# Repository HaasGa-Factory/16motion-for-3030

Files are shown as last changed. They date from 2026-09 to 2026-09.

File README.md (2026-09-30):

# Chariot pour profilé aluminium 3030

Ce dépôt est un fork du projet [mosomate/16motion](https://github.com/mosomate/16motion). Il ajoute une [adaptation mesurée pour un profilé 3030 de 29,83 × 29,95 mm](3030/README.md), avec les modèles FreeCAD, les STL prêts à imprimer, les vues d'assemblage et une animation du coulissement.

> Cette variante correspond au profilé mesuré pour ce prototype. Tous les profilés appelés « 3030 » n'ont pas nécessairement la même section. Consultez les limites de validation avant impression.

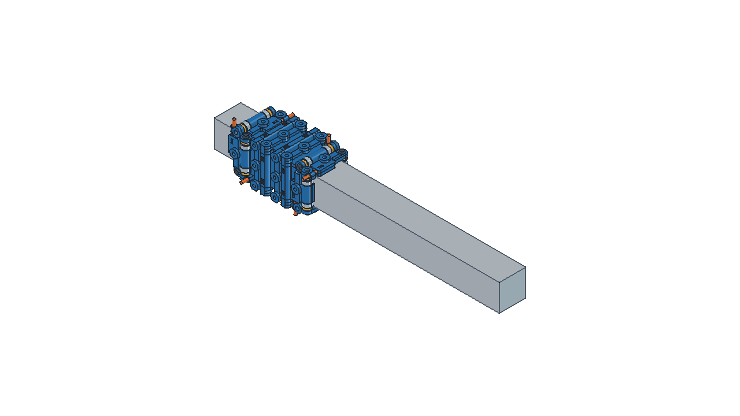
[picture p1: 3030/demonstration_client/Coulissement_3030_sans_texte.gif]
Animation du chariot 3030


## Description 16Motion ?

16Motion est un chariot configurable et imprimable en 3D pour les petits profilés aluminium jusqu'à 40 mm de largeur. Un chariot se compose de quatre plaques imprimées, assemblées autour du profilé, et de composants faciles à trouver : roulements 684 (4 × 9 × 4 mm), vis M3 et M4 et écrous M3.

Vue principale de 16Motion

Chaque plaque possède huit points de fixation permettant de monter des outils et accessoires avec des vis et écrous M3. Ils sont répartis en deux groupes : quatre **points de fixation de plaque** indiqués par les flèches jaunes et quatre **points de fixation du chariot** indiqués par les flèches violettes.

Les points de fixation du chariot traversent au moins deux plaques et augmentent donc la rigidité de l'ensemble. Si seuls les points de fixation de plaque sont utilisés, l'auteur recommande d'ajouter également des vis M3 × 16 dans quelques points de fixation du chariot.

La distance horizontale entre les points est fixée à 23 mm. La distance verticale se calcule ainsi :

`distance verticale = (largeur du profilé + 9 mm) / 2`

## Adaptation 3030 de ce fork

La section du profilé utilisé pour cette adaptation a été mesurée à **29,83 mm sur l'axe X** et **29,95 mm sur l'axe Y**. Ces deux valeurs restent séparées dans les modèles : aucune moyenne ni mise à l'échelle globale des STL n'a été appliquée.

Pour construire un chariot complet :

- imprimer **2 plaques X** depuis `Plaque_X_2983.stl` ;
- imprimer **2 plaques Y** depuis `Plaque_Y_2995.stl` ;
- imprimer **16 entretoises** depuis `Entretoise.stl`.

Les modèles, les STL, la nomenclature et les contrôles réalisés se trouvent dans le [dossier 3030](3030/README.md).

Pour imprimer directement le chariot sans préparer les plateaux soi-même, le modèle est également disponible sur [MakerWorld — 3030Pro Sliding Carriage](https://makerworld.com/fr/models/3376063-3030pro-sliding-carriage#profileId-3840481), avec le projet 3MF et son profil d'impression Bambu Studio.

## Avertissement

**L'auteur original précise qu'il n'est pas ingénieur mécanicien et que cette conception n'a pas fait l'objet d'essais professionnels. L'impression, l'assemblage et l'utilisation se font sous la responsabilité de l'utilisateur.**

Les roulements en acier roulent directement sur l'aluminium. Ils peuvent marquer ou user le profilé avec le temps. Pour une utilisation occasionnelle, l'effet peut rester limité. Pour une utilisation régulière, l'auteur conseille une légère lubrification, par exemple une fine couche de graisse au lithium.

Les vérifications CAO de cette variante ne constituent pas une validation de la capacité de charge, de l'usure ou du comportement mécanique réel. Un premier montage imprimé doit confirmer le coulissement, la précharge et l'absence de point dur sur toute la course.

## Nomenclature pour une plaque

Pour chacune des quatre plaques :

- 1 plaque imprimée en 3D ;
- 4 entretoises de roulement imprimées en 3D ;
- 2 vis M4 de longueur `largeur nominale du profilé + 10 mm` ;
- 2 vis M3 × 16 mm ;
- 2 écrous M3 autofreinés ;
- 4 roulements 684 (4 × 9 × 4 mm).

Pour la variante 3030 de ce dépôt, les axes de roulement sont des **vis M4 × 40 mm**.

## Conseils d'impression 3D

Conseils de l'auteur :

- matériau recommandé : **PETG** ;
- supports limités aux zones en contact avec le plateau ;
- épaisseur de paroi de 1 mm ;
- épaisseur supérieure et inférieure de 0,5 mm.

Les STL de la variante 3030 sont exportés en millimètres, à l'échelle 100 %, avec une déviation de surface de **0,1 mm** et une déviation angulaire de **5°**.

## Personnalisation dans FreeCAD

1. Ouvrir `Plate.FCStd` dans FreeCAD.
2. Si seule l'entretoise apparaît, afficher l'objet **Plate**. Dans ses propriétés d'apparence, sélectionner à nouveau le mode **Flat Lines**.
3. Activer temporairement **Skip recomputes** sur le document pendant la modification.
4. Dans **Spreadsheet**, modifier :
   - **Ideal extrusion width** : largeur nominale d'un côté du profilé ;
   - **Actual extrusion width** : largeur réellement mesurée.
5. Recalculer **Spreadsheet**, puis les objets dépendants **Plate**, **Spacer** et **Assets**.
6. Dans l'atelier **Mesh**, créer un maillage de **Plate** avec une déviation de surface de 0,1 mm et une déviation angulaire de 5°.
7. Créer également le maillage de **Spacer**, puis exporter les deux maillages.

Pour un profilé dont les deux dimensions mesurées diffèrent, produire deux variantes distinctes comme dans le [dossier 3030](3030/README.md). Ne pas utiliser une moyenne arbitraire.

Vidéo de personnalisation de la plaque (https://www.youtube.com/watch?v=9Bi0MCfb9tI "Personnalisation de la plaque | Série vidéo 16Motion")

## Préparation d'une plaque

1. Après impression, tarauder en M4 les trous fixes **inférieur gauche** et **supérieur droit**.
2. Insérer un écrou M3 autofreiné dans le logement situé sous un levier de précharge.
3. Introduire une vis M3 × 16 à travers le levier et la visser jusqu'à ce qu'elle touche à peine le levier.
4. Répéter l'opération pour l'autre levier.

Vidéo d'assemblage d'une plaque (https://www.youtube.com/watch?v=31CdhINwxhE "Assemblage d'une plaque | Série vidéo 16Motion")

## Assemblage du chariot

Pour le chariot complet, prévoir 16 entretoises imprimées, 16 roulements 684 et 8 vis M4 de la longueur indiquée dans la nomenclature.

1. Emboîter les quatre plaques. De longues vis M3 ou des clés Allen placées temporairement dans les points de fixation du chariot facilitent l'alignement.
2. Visser une vis M4 dans le trou taraudé d'une plaque jusqu'à ce qu'elle atteigne l'autre côté.
3. Placer une entretoise et un roulement sur le trajet de la vis M4.
4. Avancer la vis jusqu'à maintenir ce premier ensemble.
5. Ajouter une seconde entretoise et un second roulement, puis visser complètement l'axe.
6. Serrer la vis M4 sans écraser le plastique.
7. Répéter l'opération aux sept autres positions.
8. Retirer les vis ou clés utilisées temporairement pour maintenir l'alignement.

Vidéo d'assemblage du chariot (https://www.youtube.com/watch?v=4gjbtIjSXgw "Assemblage du chariot | Série vidéo 16Motion")

## Réglage de la précharge

La règle de l'auteur est simple : **aucun jeu, mais pas de tension excessive**. Régler les deux leviers d'une même paire avec une précharge aussi équilibrée que possible.

Comparaison de la précharge

1. Ébavurer légèrement les arêtes d'une extrémité du profilé.
2. Engager le chariot sur le profilé.
3. Serrer les vis d'une paire de leviers par petits incréments.
4. Faire coulisser le chariot après chaque ajustement.
5. Arrêter dès qu'une légère résistance apparaît à l'engagement.
6. Répéter pour les autres paires de leviers.

Le chariot doit encore descendre sous son propre poids lorsque le profilé est placé verticalement. S'il reste bloqué, la précharge est trop importante. Il est normal que certains roulements ne tournent pas en permanence pendant le déplacement.

Vidéo de réglage de la précharge (https://www.youtube.com/watch?v=hf6m5ihSEW8 "Réglage de la précharge | Série vidéo 16Motion")

## Licence et attribution

Conception originale : [mosomate/16motion](https://github.com/mosomate/16motion).

Ce travail est distribué sous licence [Creative Commons Attribution — Pas d'utilisation commerciale 4.0 International][cc-by-nc]. Cette adaptation conserve la même licence et n'accorde aucun droit supplémentaire.

[][cc-by-nc]

[cc-by-nc]: https://creativecommons.org/licenses/by-nc/4.0/
[cc-by-nc-image]: https://licensebuttons.net/l/by-nc/4.0/88x31.png

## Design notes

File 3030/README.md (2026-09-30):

# Adaptation 3030 — prototype mesuré

Cette variante du projet [mosomate/16motion](https://github.com/mosomate/16motion) conserve le modèle paramétrique de l'auteur et ses dimensions de quincaillerie. Elle est adaptée à **un profilé mesuré à 29,83 × 29,95 mm**, pas à tous les profilés 3030.

Coulissement du chariot

## Pièces à imprimer

| Pièce | Quantité | STL | Modèle paramétrique |
|---|---:|---|---|
| Plaque X, largeur réelle 29,83 mm | 2 | [STL X](mesures_2983_2995/Plaque_X_2983.stl) | [FreeCAD X](mesures_2983_2995/Plaque_X_2983.FCStd) |
| Plaque Y, largeur réelle 29,95 mm | 2 | [STL Y](mesures_2983_2995/Plaque_Y_2995.stl) | [FreeCAD Y](mesures_2983_2995/Plaque_Y_2995.FCStd) |
| Entretoise commune | 16 | [STL](mesures_2983_2995/Entretoise.stl) | Objet Spacer dans les modèles ci-dessus |

STL en millimètres, à imprimer à 100 %. Déviation de surface 0,1 mm et angulaire 5°. Aucun STL n'a subi de mise à l'échelle globale. Ne pas imprimer quatre fois la même variante de plaque.

## Projet Bambu Studio prêt à trancher

Le fichier [plaqueXY-entretoise.3mf](../Bambustudio/plaqueXY-entretoise.3mf) regroupe toutes les pièces nécessaires :

- **plateau 1** : 2 plaques X et 2 plaques Y ;
- **plateau 2** : 17 entretoises, dont 16 pour le montage et 1 de secours.

Réglages enregistrés dans le projet : **Bambu Lab H2S**, buse **0,4 mm**, couches de **0,20 mm**, **PETG**, deux parois, remplissage grille à 15 %, supports arborescents automatiques limités au plateau et plateau PEI texturé.

Le 3MF contient la disposition des pièces et les paramètres de tranchage, mais pas un G-code universel. Avant impression, choisir dans Bambu Studio l'imprimante, la buse, le plateau et le filament réellement installés, relancer le tranchage puis vérifier chaque couche dans l'aperçu. Sur une autre imprimante, conserver les géométries et adapter les vitesses, températures, refroidissement et supports au matériel utilisé.

## Montage et quincaillerie

La [notice en français](mesures_2983_2995/NOTICE_FR.md) précise les paramètres, l'orientation des plaques et le réglage de précharge. Pour un chariot : 16 roulements 684 (4 × 9 × 4 mm), 8 vis M4 × 40 mm, 8 vis M3 × 16 mm et 8 écrous M3 autofreinés. Les avant-trous fixes des plaques sont à tarauder M4 ; les fixations d'accessoires sont supplémentaires.

[Assemblage FreeCAD](mesures_2983_2995/Assemblage_mesure.FCStd) · [Vue éclatée FreeCAD](mesures_2983_2995/Eclate_mesure.FCStd) · [Image éclatée](mesures_2983_2995/Eclate_mesure.png)

## Démonstration du coulissement

[GIF sans texte](demonstration_client/Coulissement_3030_sans_texte.gif) · [Scène FreeCAD](demonstration_client/Demonstration_3030.FCStd) · [Macro](demonstration_client/Demonstration_3030.FCMacro)

Le GIF montre une course illustrative de 180 mm sur un rail de 320 mm. Pour déplacer la scène FreeCAD, modifier `Commande.Position` entre −90 et +90 mm. La macro s'exécute dans FreeCAD et charge l'assemblage du dossier voisin ; conserver cette arborescence. Elle propose lecture/pause, curseur et transparence des plaques. Les modèles de fabrication ne sont pas modifiés.

## Vérifications et limites

Les rapports [du prototype](mesures_2983_2995/verification_mesures.json) et [de l'animation](demonstration_client/verification.json) consignent les contrôles réalisés dans FreeCAD 1.1.3 : recalculs, géométrie, fermeture et dimensions des maillages, positions de présentation.

Le rail est une enveloppe rectangulaire simplifiée : coins et rainures ne sont pas modélisés. L'appui des roulements sur les plats est partiel. La précharge nécessite un réglage réel ; les interférences de la pose rigide sont expliquées dans la notice. L'animation impose la translation et ne simule ni rotation des roulements, ni frottements, ni déformations, ni capacité de charge. Le coulissement et la tenue mécanique restent à vérifier sur un premier montage imprimé et sur toute sa course.

## Origine et licence

Conception originale : **mosomate / 16motion**. Modifications de cette variante : valeurs du tableur pour les deux paires, exports STL, présentations d'assemblage, animation et documentation. Le `Plate.FCStd` original reste inchangé à la racine.

Licence originale **CC BY-NC 4.0**, conservée dans [LICENSE](../LICENSE). La clause non commerciale s'applique ; cette adaptation n'accorde pas de droits supplémentaires.

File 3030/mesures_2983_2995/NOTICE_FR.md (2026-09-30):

# 16motion adapté à 29,83 × 29,95 mm — prototype

Cette variante utilise les mesures du profilé du prototype : **X = 29,83 mm, Y = 29,95 mm**, ouverture G = 8,07 mm et plats P gauche/droite = 8,17 mm. Aucun calcul de moyenne entre X et Y. L'appui partiel des roulements sur les plats est conservé pour ce prototype.

## Fichiers à utiliser et quantités

| Pièce | Modèle paramétrique | STL | Quantité |
|---|---|---|---:|
| Paire X | `Plaque_X_2983.FCStd` | `Plaque_X_2983.stl` | **2** |
| Paire Y | `Plaque_Y_2995.FCStd` | `Plaque_Y_2995.stl` | **2** |
| Entretoise commune | Objet Spacer dans les deux modèles | `Entretoise.stl` | **16 au total** |

Ne pas imprimer quatre fois la même plaque et ne pas mélanger avec les STL nominaux 30/30 du modèle nominal. Marquer X ou Y au feutre sur les impressions pour les distinguer. Les petites différences se voient difficilement à l'œil.

`Assemblage_mesure.FCStd` contient les quatre plaques, 16 roulements, 16 entretoises, huit tiges M4 et huit tiges M3 de réglage. `Eclate_mesure.FCStd` s'ouvre directement dans la vue éclatée. Ces présentations utilisent des copies et liens internes, à régénérer après modification des modèles maîtres.

## Orientation des deux paires

Repère des mesures de section : **X** est la distance de 29,83 mm entre faces gauche/droite ; **Y** la distance de 29,95 mm entre faces haut/bas.

- Les deux **plaques X** se montent sur les côtés **haut et bas** ; leurs roulements roulent sur les faces gauche/droite, écartées de X.
- Les deux **plaques Y** se montent sur les côtés **gauche et droit** ; leurs roulements roulent sur les faces haut/bas, écartées de Y.

La lettre indique donc la dimension contrôlée par les roulements, et non la normale à la plaque. Dans FreeCAD, l'axe longitudinal du rail s'appelle aussi X : ce repère CAO est distinct de celui des mesures de section. Les étiquettes des plaques dans l'arbre reprennent les lettres des photos.

## Paramètres et fidélité au modèle

Dans `Spreadsheet`, **B3 (Ideal extrusion width) reste à 30 mm** sur les deux variantes. **B4 (Actual extrusion width) vaut 29,83 mm pour X et 29,95 mm pour Y**. B1 = 0,1 mm de compensation d'impression, B6 = 4 mm et B7 = 5 mm sont inchangés. Les 204 objets, les expressions, les logements et les leviers de l'auteur sont conservés. Seules les valeurs du tableur, les annotations et l'affichage changent.

Les plans d'emboîtement restent à 16 mm du centre, selon le paramétrage nominal du modèle. Les axes fixes sont à B4/2 + 4,45 mm et les axes réglables à B4/2 + 4,7 mm. Les positions des roulements et des vis de présentation suivent ces valeurs pour chaque paire. La visserie et les entretoises ne sont pas mises à l'échelle.

STL : **mm**, échelle 100 %, déviation de surface **0,1 mm**, angulaire **5°**, non relative. Maillages réimportés et comparés aux dimensions des solides ; détails dans `verification_mesures.json`. Les deux pièces sont visibles dans chaque modèle, l'entretoise étant décalée à X = 58 mm pour l'affichage seulement. Les STL sont exportés avant ce décalage.

## Quincaillerie et montage

Pour le chariot complet : **16 roulements 684 (4 × 9 × 4 mm), 8 vis M4 × 40 mm, 8 vis M3 × 16 mm et 8 écrous M3 autofreinés**, plus les fixations propres aux accessoires. Matériau conseillé par l'auteur : PETG, supports depuis le plateau. Les têtes/filets et écrous ne sont pas détaillés dans la présentation.

1. Ébavurer les pièces et dégager les fentes des leviers sans amincir leurs charnières.
2. Tarauder M4 les deux avant-trous fixes Ø3,7 mm en diagonale sur chaque plaque ; conserver les passages Ø4,2 mm.
3. Installer les écrous M3 et les vis de réglage au simple contact, sans précharger.
4. Emboîter les deux paires dans l'orientation indiquée. Ajouter les couples entretoise/roulement sur les axes M4, relief de l'entretoise tourné vers le roulement. Ne pas forcer les axes désalignés ; serrer sans écraser le plastique.
5. Vérifier que les bagues extérieures tournent librement, engager sur l'extrémité ébavurée du profilé puis régler progressivement par paires. Garder un coulissement libre sur la course entière. Selon le critère de l'auteur, le chariot doit encore descendre sous son poids sur un profilé vertical ; le retenir à la main.

## Appui partiel accepté et limites du prototype

Les K calculés valent **2,71 mm pour une face large de X** et **2,77 mm pour une face large de Y**, sous l'hypothèse de coins symétriques et des mêmes G/P sur les faces concernées. Ce ne sont pas des rayons certifiés. Avec les dimensions mesurées et l'empilement de cette présentation, la largeur projetée du roulement au-dessus du vrai plat est estimée à **environ 3,21 mm sur 4 mm**. Il s'agit d'un recouvrement géométrique, pas d'une mesure de la surface de contact sous charge.

Le rail reste une enveloppe rectangulaire de **29,83 × 29,95 mm**. La forme exacte des coins et l'intérieur des rainures n'ont pas été inventés. Les roulements fixes (objets `Roulement684_i_2` et `Roulement684_i_3`, i = 0 à 3) présentent toujours 0,05 mm de pénétration théorique dans cette enveloppe, tandis que les réglables ont 0,20 mm de jeu. Le décalage d'axes de 0,25 mm au repos nécessite déplacement et/ou inclinaison au montage. Les intersections avec les tiges simplifiées sont consignées, et les intersections M4/avant-trou doivent être distinguées du taraudage non représenté.

Les contrôles CAO vérifient solides, recalculs, maillages et interférences de la pose rigide. Ils ne simulent pas les déformations, le réglage de précharge, la charge admissible ou l'usure. Vérifier sur ce premier montage : rotation, absence de blocage et de jeu, appuis, alignement, tenue des taraudages, absence de fissure des leviers et de marques excessives sur l'aluminium. Les mesures le long de toute la course n'ont pas été fournies ; le coulissement reste donc à vérifier sur cette longueur.

Source : **mosomate / 16motion**, https://github.com/mosomate/16motion — licence **CC BY-NC 4.0**. Le modèle original est conservé à la racine du dépôt. Pour reproduire les variantes, ouvrir une copie de `Plate.FCStd`, régler B3 à 30 mm et B4 à 29,83 mm (paire X) ou 29,95 mm (paire Y), puis recalculer le tableur, Plate, Spacer et Assets. Exporter Plate et Spacer avec les réglages de maillage indiqués ci-dessus. Les documents de présentation sont des copies de formes et doivent être actualisés séparément après toute modification.

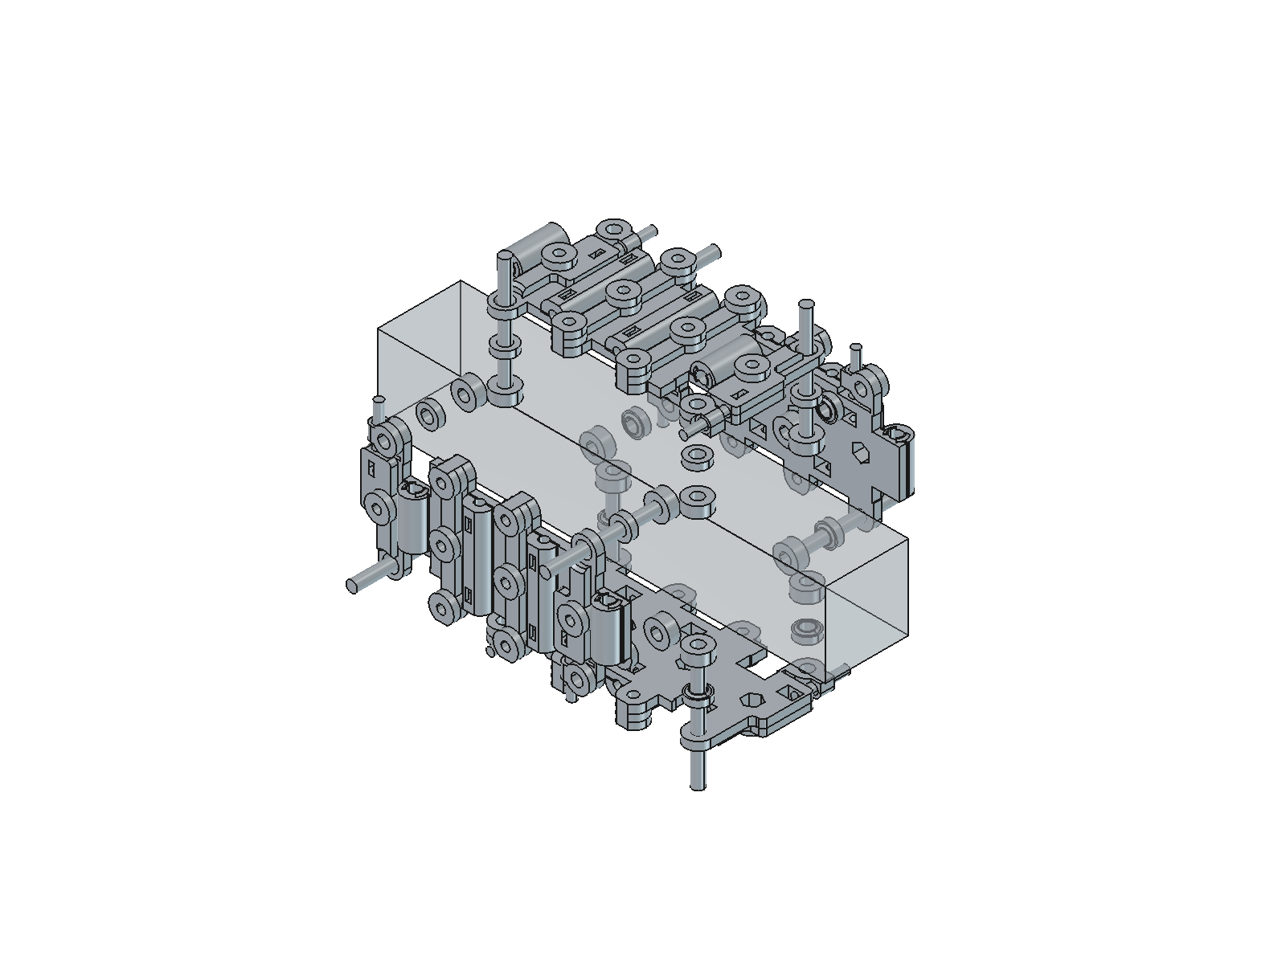
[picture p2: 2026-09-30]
3030/mesures_2983_2995/Eclate_mesure.png

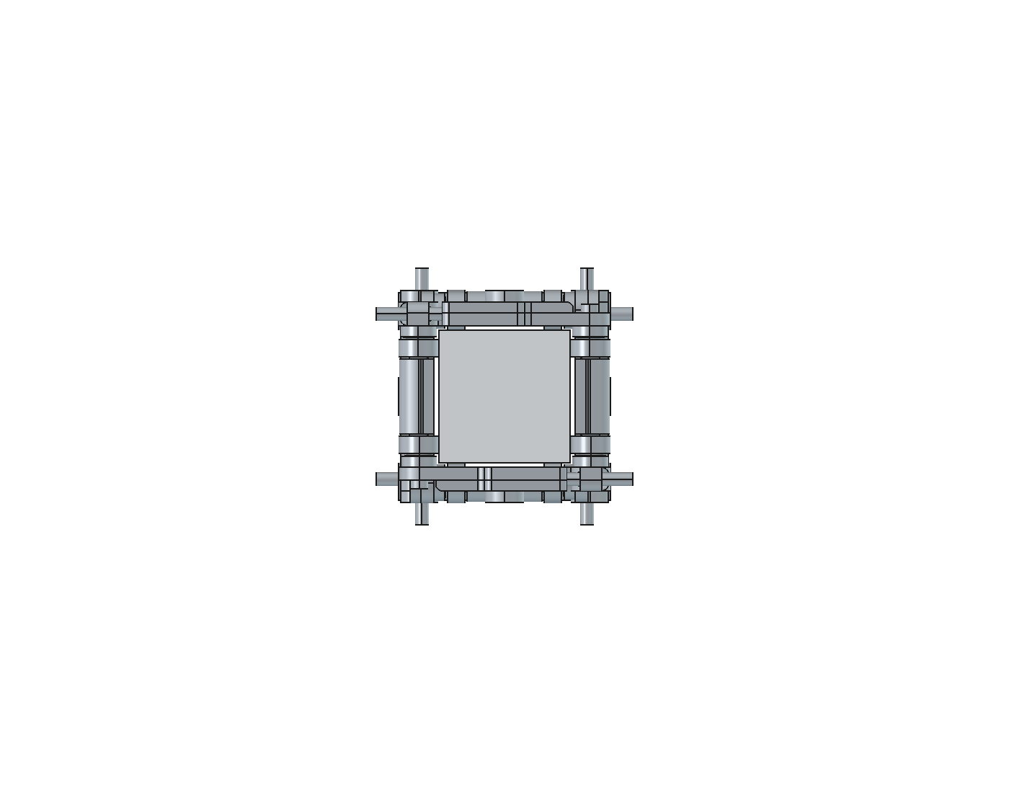
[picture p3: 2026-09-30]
3030/mesures_2983_2995/Section_mesuree.png

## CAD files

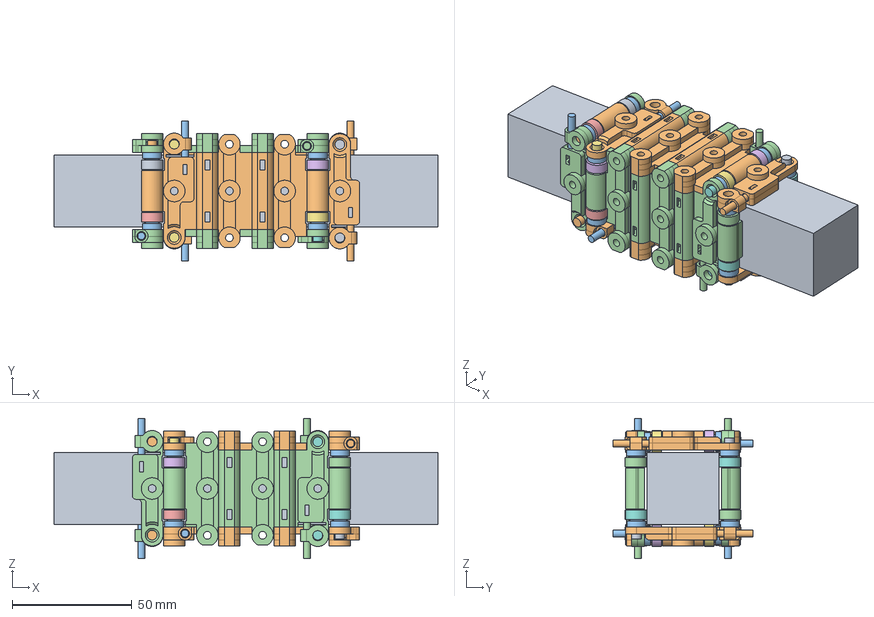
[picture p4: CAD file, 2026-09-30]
3030/mesures_2983_2995/Assemblage_mesure.FCStd
160.0 x 58.2 x 58.3 mm
Enveloppe 29.83 x 29.95 - coins et rainures non modelises
PlateSource x 2
SpacerSource x 16
Roulement684_0_0
Roulement684_0_1
Roulement684_0_2
VisM4x40_0_2
Roulement684_0_3
VisM4x40_0_3
ReglageM3x16_0_0
ReglageM3x16_0_1
Roulement684_1_0
Roulement684_1_1
Roulement684_1_2
VisM4x40_1_2
Roulement684_1_3
VisM4x40_1_3
ReglageM3x16_1_0
ReglageM3x16_1_1
PlateSourceY x 2
Roulement684_2_0
Roulement684_2_1
Roulement684_2_2
VisM4x40_2_2
Roulement684_2_3
VisM4x40_2_3
ReglageM3x16_2_0
ReglageM3x16_2_1
Roulement684_3_0
Roulement684_3_1
Roulement684_3_2
VisM4x40_3_2
Roulement684_3_3
VisM4x40_3_3
ReglageM3x16_3_0
ReglageM3x16_3_1

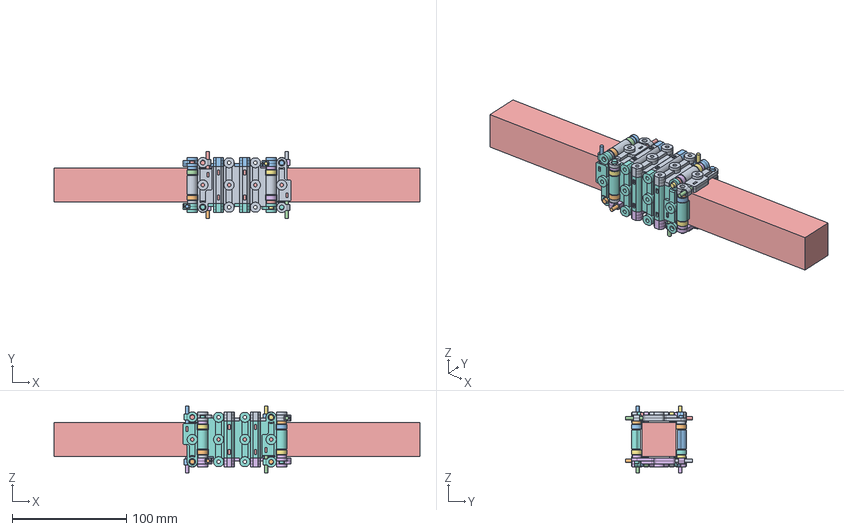
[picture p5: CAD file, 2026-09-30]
3030/demonstration_client/Demonstration_3030.FCStd
320.0 x 58.2 x 58.3 mm
Plaque X 1 - B4 29.83
Entretoise_0_0
Roulement684_0_0
Entretoise_0_1
Roulement684_0_1
Entretoise_0_2
Roulement684_0_2
VisM4x40_0_2
Entretoise_0_3
Roulement684_0_3
VisM4x40_0_3
ReglageM3x16_0_0
ReglageM3x16_0_1
Plaque X 2 - B4 29.83
Entretoise_1_0
Roulement684_1_0
Entretoise_1_1
Roulement684_1_1
Entretoise_1_2
Roulement684_1_2
VisM4x40_1_2
Entretoise_1_3
Roulement684_1_3
VisM4x40_1_3
ReglageM3x16_1_0
ReglageM3x16_1_1
Plaque Y 1 - B4 29.95
Entretoise_2_0
Roulement684_2_0
Entretoise_2_1
Roulement684_2_1
Entretoise_2_2
Roulement684_2_2
VisM4x40_2_2
Entretoise_2_3
Roulement684_2_3
VisM4x40_2_3
ReglageM3x16_2_0
ReglageM3x16_2_1
Plaque Y 2 - B4 29.95
Entretoise_3_0
Roulement684_3_0
Entretoise_3_1
Roulement684_3_1
Entretoise_3_2
Roulement684_3_2
VisM4x40_3_2
Entretoise_3_3
Roulement684_3_3
VisM4x40_3_3
ReglageM3x16_3_0
ReglageM3x16_3_1
3030 — enveloppe 29,83 x 29,95 — longueur illustrative 320 mm

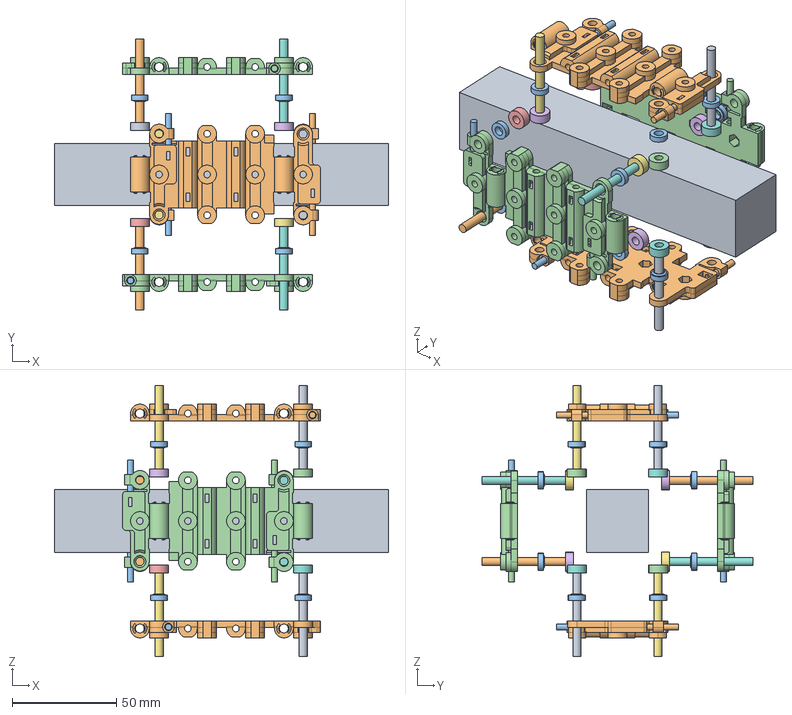
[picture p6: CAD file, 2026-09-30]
3030/mesures_2983_2995/Eclate_mesure.FCStd
160.0 x 130.0 x 130.0 mm
ProfileEclate
PlateSource x 2
SpacerSource x 16
RoulementEclate_0_0
RoulementEclate_0_1
RoulementEclate_0_2
VisM4Eclatee_0_2
RoulementEclate_0_3
VisM4Eclatee_0_3
ReglageEclate_0_0
ReglageEclate_0_1
RoulementEclate_1_0
RoulementEclate_1_1
RoulementEclate_1_2
VisM4Eclatee_1_2
RoulementEclate_1_3
VisM4Eclatee_1_3
ReglageEclate_1_0
ReglageEclate_1_1
PlateSourceY x 2
RoulementEclate_2_0
RoulementEclate_2_1
RoulementEclate_2_2
VisM4Eclatee_2_2
RoulementEclate_2_3
VisM4Eclatee_2_3
ReglageEclate_2_0
ReglageEclate_2_1
RoulementEclate_3_0
RoulementEclate_3_1
RoulementEclate_3_2
VisM4Eclatee_3_2
RoulementEclate_3_3
VisM4Eclatee_3_3
ReglageEclate_3_0
ReglageEclate_3_1

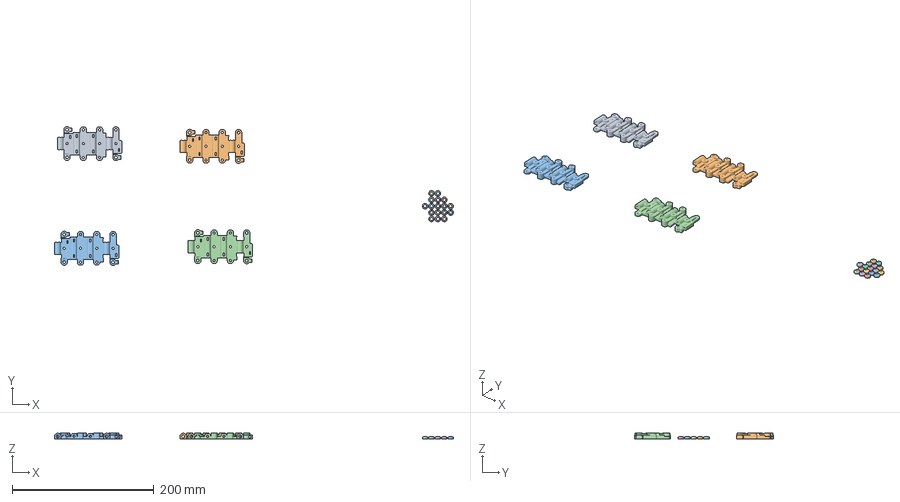
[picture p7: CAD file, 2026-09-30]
Bambustudio/plaqueXY-entretoise.3mf
562.8 x 196.0 x 8.00 mm
Plaque_X_2983.stl x 2
Plaque_Y_2995.stl x 2
Entretoise.stl x 17

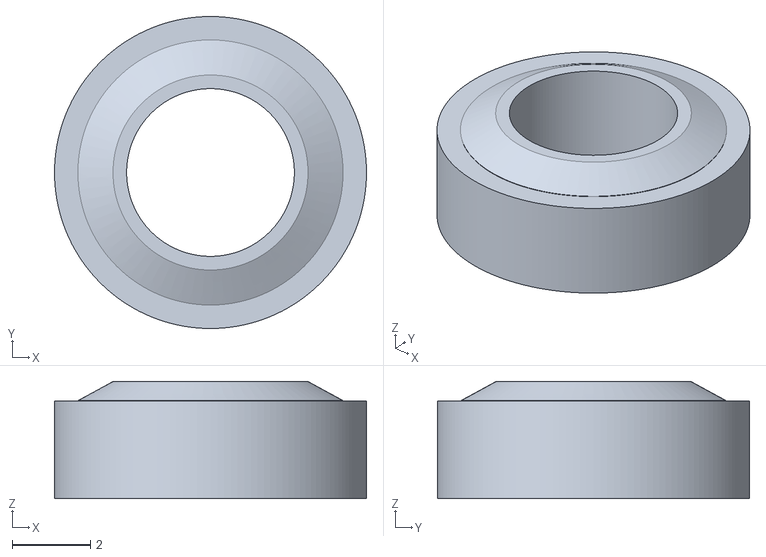
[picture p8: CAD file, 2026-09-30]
3030/mesures_2983_2995/Entretoise.stl
8.00 x 8.00 x 3.00

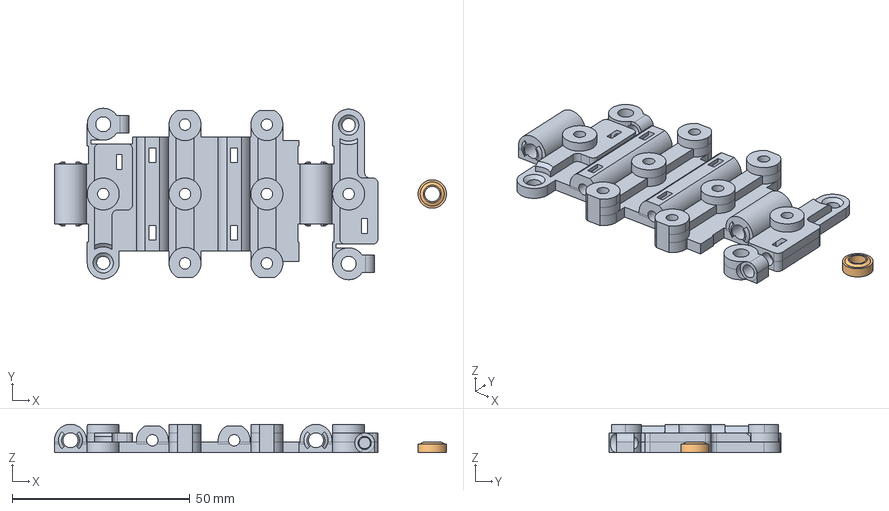
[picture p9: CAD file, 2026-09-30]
3030/mesures_2983_2995/Plaque_X_2983.FCStd
110.2 x 48.2 x 8.00 mm
Plate
Spacer

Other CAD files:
3030/mesures_2983_2995/Plaque_Y_2995.FCStd
3030/mesures_2983_2995/Plaque_X_2983.stl
3030/mesures_2983_2995/Plaque_Y_2995.stl

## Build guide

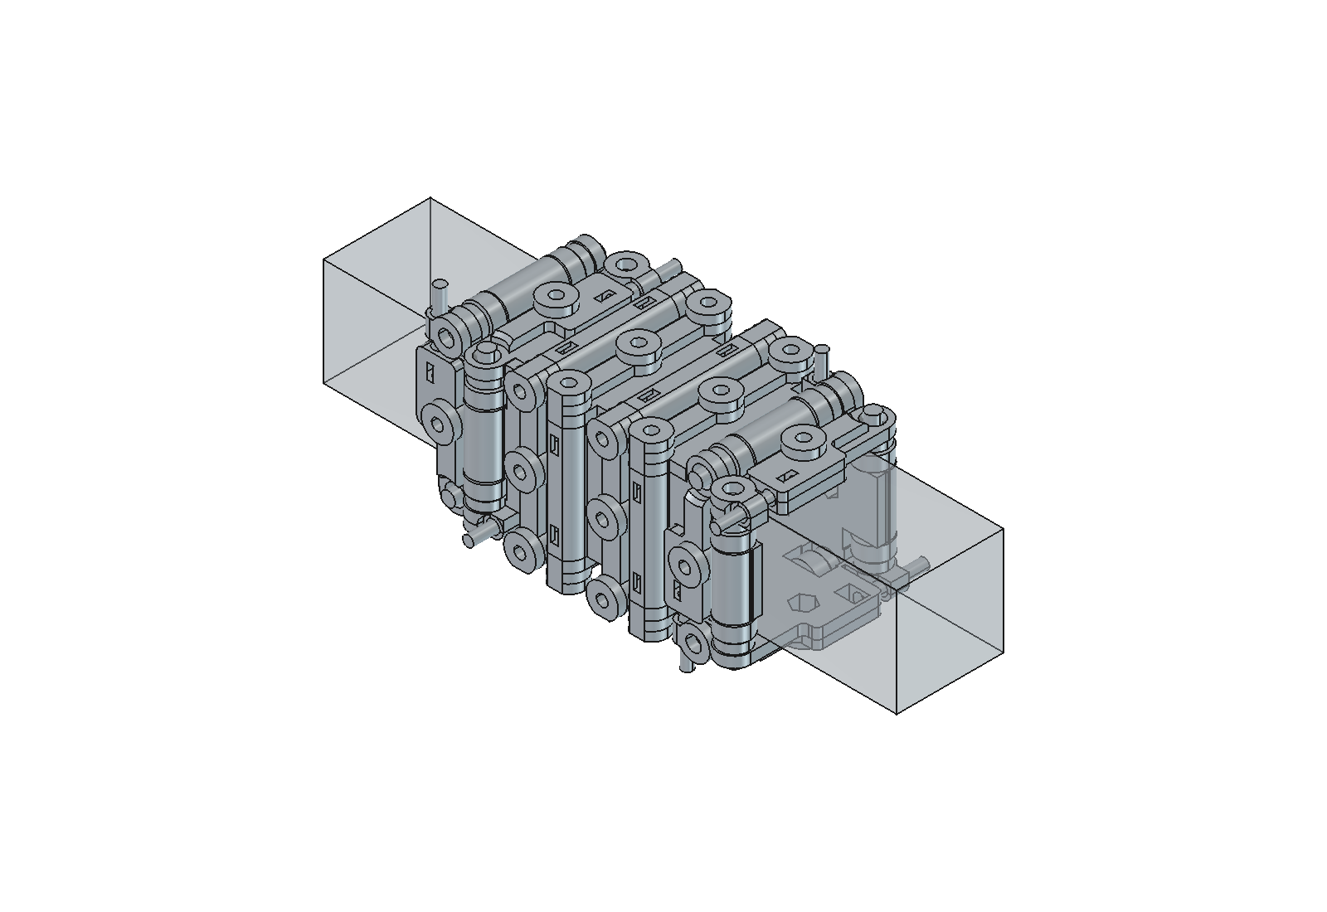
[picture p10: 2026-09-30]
3030/mesures_2983_2995/Assemblage_mesure.png

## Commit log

2026-09-30 16motion-for-3030
    adaptation pour profil 3030
    [Assemblage_mesure.FCStd, Demonstration_3030.FCStd, Eclate_mesure.FCStd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]
2026-09-30 publication makerworld
    envoie profil d'impression
    [plaqueXY-entretoise.3mf]
